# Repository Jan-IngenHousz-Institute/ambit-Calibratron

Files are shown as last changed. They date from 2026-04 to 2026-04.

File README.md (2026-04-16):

# Mini PAR meter - minimum tool to get a good numerical sense of light intensity

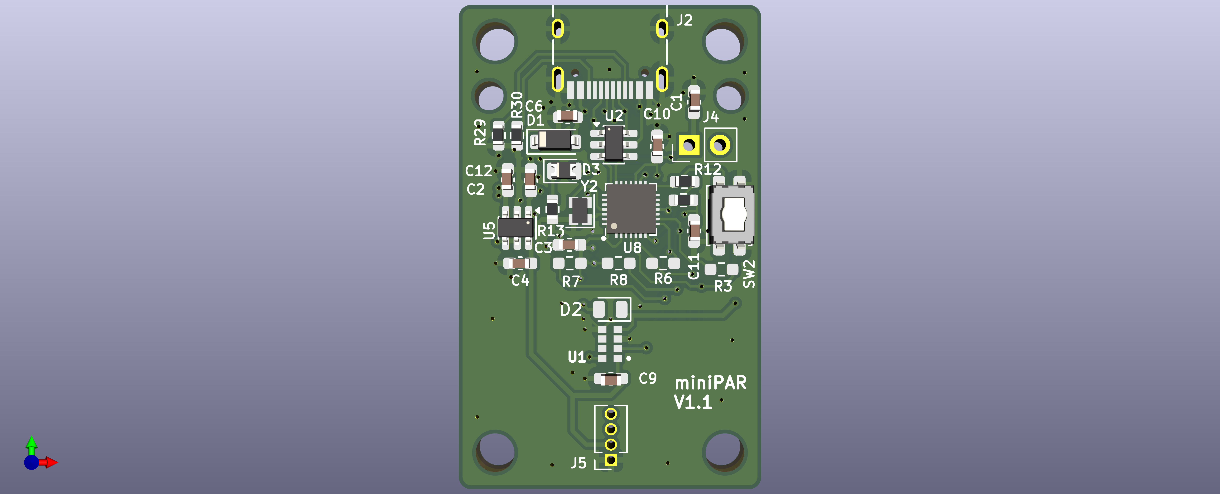
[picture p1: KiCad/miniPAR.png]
vis


# Commands

* to be added
* "reboot" -> 
    - Response: series of lines with info. 
    - ends with the "Ready" line
* "hello" -> 
    - Response: "MiniPAR,V" + version
* "spec" ->
    - Response: {"spectrometer":{"model":"AS7341","channels":{"f1_415":117,"f2_445":602,"f3_480":732,"f4_515":839,"f5_555":1606,"f6_590":1711,"f7_630":1765,"f8_680":1041,"clear":3704,"nir":359}}}
* "set_led"+ current value in mA ->
    - Response:  {"spectrometer":{"led_current_ma":20}} 
    - Example for 20mA
* "par" -> 
    - Response: 123.45
    - Read back par vale. This is a par_raw scaled by y=ax+b
* "par_raw"
    - Response: 1.23 
    - The weighted sum of the channel counts
* "cal_par_slope," + slope -> 
    - Response: 10.0
    - Example for slope = 10.0
    - Set the "a" coefficient for y=ax+b scaling
* "cal_par_ntercept," + intercept -> 
    - Response: 2.3
    - Example for intercept = 2.3
    - Set the "b" coefficient for y=ax+b scaling

# Protocol 

* terminator: "\r"
* PAR uinits - µmol/m²/s"

FW Design (L. Caracciolo),

HW Design (L. Grabowski)

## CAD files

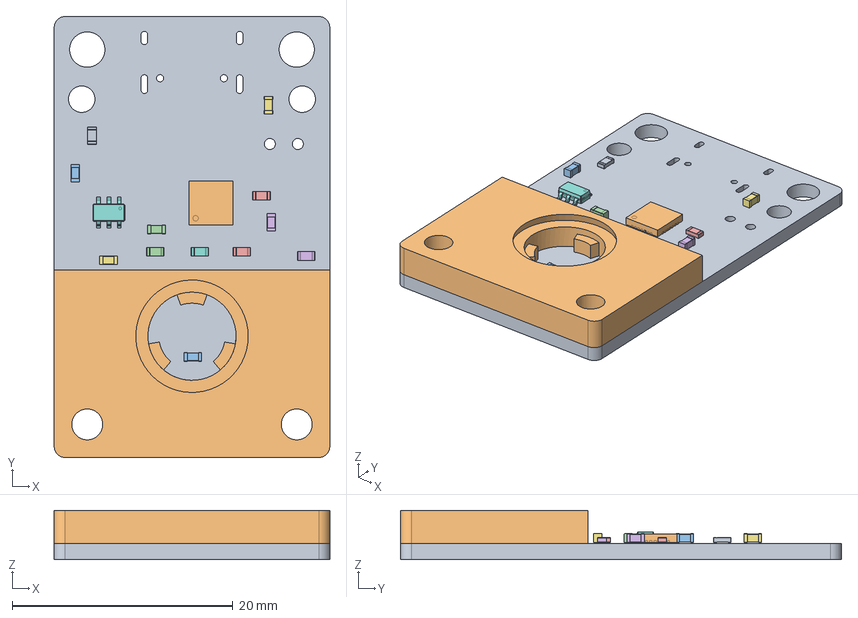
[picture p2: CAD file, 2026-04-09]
Case/diffuserHolder.FCStd
25.0 x 40.0 x 4.46 mm
caliTool_PCB
Insert
C_0603_1608Metric008
R_0603_1608Metric006
R_0603_1608Metric005
C_0603_1608Metric004
C_0603_1608Metric003
R_0603_1608Metric004
R_0603_1608Metric003
QFN-28-1EP_4x4mm_P0.4mm_EP2.4x2.4mm
C_0603_1608Metric002
C_0603_1608Metric001
R_0603_1608Metric002
R_0603_1608Metric001
C_0603_1608Metric
TSOT-23-6

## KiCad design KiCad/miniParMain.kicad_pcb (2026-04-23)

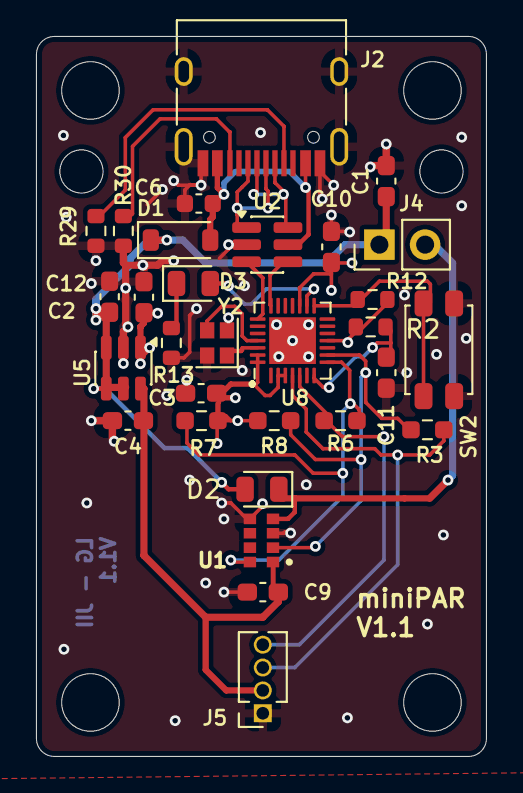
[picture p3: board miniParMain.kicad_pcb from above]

Board: 4 copper layers, 25.0 x 40.0 mm, 30 parts (0 on the bottom side), 22 nets.

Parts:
C1, C2, C3, C4, C9, C10, C11, C12: 2.2u; C_0603_1608Metric_Pad1.08x0.95mm_HandSolder
C6: 10u; C_0603_1608Metric
D1: 1N4148WT; D_SOD-123
D2, D3: LED; D_0805_2012Metric
J2: USB_C_Receptacle; USB_C_Receptacle_HRO_TYPE-C-31-M-12
J4: Conn_01x02_Pin; PinHeader_1x02_P2.54mm_Vertical
J5: secondBoard; PinSocket_1x04_P1.27mm_Vertical
R2, R12, R13, R29, R30: 5.1K; R_0603_1608Metric
R3, R6: 0R; R_0603_1608Metric_Pad0.98x0.95mm_HandSolder
R7, R8: 10K; R_0603_1608Metric_Pad0.98x0.95mm_HandSolder
SW2: SW_Push; SW_SPST_EVQP2_ShortPushTravel_H2.1mm
U1: AS7341-DLGT; PSON80P310X200X110-8N
U2: IP4234CZ6; SC-74-6_1.55x2.9mm_P0.95mm
U5: AP7312-1833W6-7; TSOT-23-6
U8: ESP8685; QFN-28-1EP_4x4mm_P0.4mm_EP2.6x2.6mm
Y2: 40MHz; Crystal_SMD_2016-4Pin_2.0x1.6mm

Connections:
BOOT: R12.1, SW2.1, U8.15 (GPIO9/BOOT)
CC1: J2.A5 (CC1), R29.2
CC2: J2.B5 (CC2), R30.2
D+: U2.3, U8.22 (GPIO19/USB_D+)
D-: U2.4, U8.21 (GPIO18/USB_D-)
GND: C1.2, C2.2, C3.2, C4.2, C6.1, C9.2, C10.2, C11.2, C12.2, J2.A1 (GND), J2.A12 (GND), J2.B1 (GND), J2.B12 (GND), J2.S1 (SHIELD), J5.1, R13.1, R29.1, R30.1, SW2.2, U1.3 (GND), U1.5 (PGND), U2.2 (VN), U5.2 (GND), U8.29 (GND), Y2.2, Y2.4
LED1ACT: D2.1 (K), J4.2, U1.4 (LDR)
unnamed: D3.2 (A), U8.16 (GPIO10)
unnamed: D3.1 (K), R13.2
unnamed: J2.A6 (D+), J2.B6 (D+), U2.1
unnamed: J2.A7 (D-), J2.B7 (D-), U2.6
unnamed: U8.25 (XTAL_N), Y2.3
unnamed: U8.26 (XTAL_P), Y2.1
SCL: R3.2, R8.1, U1.2 (SCL), U8.9 (MTMS/GPIO4/ADC1_CH4)
SCL_2: J5.4, R6.1, U8.5 (GPIO1/XTAL_32K_N/ADC1_CH1)
SDA: R6.2, R7.1, U1.8 (SDA), U8.8 (GPIO3/ADC1_CH3)
SDA_2: J5.3, R3.1, U8.4 (GPIO0/XTAL_32K_P/ADC1_CH0)
V+: C1.1, C12.1, D1.1 (K), D2.2 (A), J4.1, U5.3 (EN2), U5.4 (EN1), U5.5 (VIN)
V+1.8V: C4.1, C9.1, J5.2, U1.1 (VDD), U5.6 (VOUT_1V8)
V+3V: C2.1, C3.1, C10.1, R2.1, R7.2, R8.2, R12.2, U5.1 (VOUT_3V3), U8.2 (VDD3P3), U8.3 (VDD3P3), U8.11 (VDD3P3_RTC), U8.17 (VDD3P3_CPU), U8.27 (VDDA), U8.28 (VDDA)
Vusb: C6.2, D1.2 (A), J2.A4 (VBUS), J2.A9 (VBUS), J2.B4 (VBUS), J2.B9 (VBUS), U2.5 (VP)
reset_EN: C11.1, R2.2, U8.7 (CHIP_EN)

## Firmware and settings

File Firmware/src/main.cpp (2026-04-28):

#include <Arduino.h>
#include <Wire.h>
#include "app/commands.h"
#include "app/spectrometer_api.h"


String line;
enum class RxMode { UNKNOWN, LINE, JSON };
String rx;
RxMode mode = RxMode::UNKNOWN;
int braceDepth = 0;   // {}
int bracketDepth = 0; // []
bool inString = false;
char prev = 0;

void resetRx() {
  rx = "";
  mode = RxMode::UNKNOWN;
  braceDepth = 0;
  bracketDepth = 0;
  inString = false;
  prev = 0;
}

void setup() {
  
  Serial.begin(115200);

  Wire.begin(3, 4);
  
  loadpref();
  // Spectrometer detection and backend initialization
  initSpectrometer();
  Serial.println(F("Ready"));

  

}
 


void loop() {
while (Serial.available() > 0) {
    char c = (char)Serial.read();
    if (c == '\r')
      continue;

    rx += c;

    // Decide mode once we see the first non-whitespace char
    if (mode == RxMode::UNKNOWN) {
      // find first non-space char in the current buffer
      int i = 0;
      while (i < (int)rx.length() && isspace((unsigned char)rx[i]))
        i++;
      if (i < (int)rx.length()) {
        char first = rx[i];
        if (first == '{' || first == '[') {
          mode = RxMode::JSON; // start JSON mode (typically openJII app series of commands)
        } else {
          mode = RxMode::LINE; // start LINE mode (simple single-line commands)
        }
      }
    }

    // LINE mode: only process on newline
    if (mode == RxMode::LINE) {
      if (c == '\n') {
        rx.trim();
        if (rx.length() > 0)
          handleCommandText(rx);
        Serial.println();
        resetRx();
      }
      continue;
    }

    // JSON mode: track braces/brackets until outermost closes
    if (mode == RxMode::JSON) {
      if (c == '"' && prev != '\\')
        inString = !inString;

      if (!inString) {
        if (c == '{')
          braceDepth++;
        else if (c == '}')
          braceDepth--;
        else if (c == '[')
          bracketDepth++;
        else if (c == ']')
          bracketDepth--;
      }

      prev = c;

      // Only declare "complete" after the top-level JSON object/array closes.
      if (!inString && braceDepth == 0 && bracketDepth == 0) {
        rx.trim();
        bool ok = handleJsonProtocol(rx);
        if (!ok)
          Serial.println(F("{\"error\":\"json_dispatch_failed\"}"));
        resetRx();
      }
      continue;
    }

    // Safety: prevent runaway buffer
    if (rx.length() > 2048) {
      Serial.println("rx_overflow");
      resetRx();
    }
  }
}

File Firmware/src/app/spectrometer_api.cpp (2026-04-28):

#include <Arduino.h>
#include <Wire.h>
#include <Preferences.h>

#include "app/as7341_api.h"
#include "app/as7343_api.h"
#include "app/spectrometer_api.h"

// ---------------------------------------------------------------------------
// Global state
// ---------------------------------------------------------------------------
bool spectrometer_available = false;
SpectrometerModel spectrometer_model = SpectrometerModel::None;

// Transitional shim: keep as7341_available for the Phase 2 if-else command path.
// Removed in Phase 3 once the dispatch table takes over.
bool as7341_available = false;

// ---------------------------------------------------------------------------
// Board-level LED policy
// ---------------------------------------------------------------------------
constexpr uint16_t kSpectrometerLedBoardMaxMa = 20;
constexpr uint16_t kLedSetFailed = 0xFFFF;

// ---------------------------------------------------------------------------
// Channel name tables
// ---------------------------------------------------------------------------
static const char * const kAs7341ChannelNames[10] = {
  "f1_415", "f2_445", "f3_480", "f4_515",
  "f5_555", "f6_590", "f7_630", "f8_680",
  "clear",  "nir"
};

// AS7343 bringup names — 18 entries matching Adafruit as7343_channel_t DATA register order.
// Used when channel_count == 18 (AS7343_BRINGUP_RAW_DUMP active).
// DELETE together with the bringup path once the semantic table is frozen.
static const char * const kAs7343BringupNames[18] = {
  "fz_450",    // DATA[0]  FZ  450nm
  "fy_555",    // DATA[1]  FY  555nm
  "fxl_600",   // DATA[2]  FXL 600nm
  "nir",       // DATA[3]  NIR 855nm
  "vis_tl_0",  // DATA[4]  VIS clear cycle 1 top-left
  "vis_br_0",  // DATA[5]  VIS clear cycle 1 both-right
  "f2_425",    // DATA[6]  F2  425nm
  "f3_475",    // DATA[7]  F3  475nm
  "f4_515",    // DATA[8]  F4  515nm
  "f6_640",    // DATA[9]  F6  640nm
  "vis_tl_1",  // DATA[10] VIS clear cycle 2 top-left
  "vis_br_1",  // DATA[11] VIS clear cycle 2 both-right
  "f1_405",    // DATA[12] F1  405nm
  "f7_690",    // DATA[13] F7  690nm
  "f8_745",    // DATA[14] F8  745nm
  "f5_550",    // DATA[15] F5  550nm
  "vis_tl_2",  // DATA[16] VIS clear cycle 3 top-left
  "vis_br_2",  // DATA[17] VIS clear cycle 3 both-right
};

// AS7343 semantic names — 13 entries for production mode (channel_count == 13).
// Channels sorted wavelength-ascending; clear derived from VIS averages; nir last.
// TODO: confirm this ordering from bring-up evidence before switching off bringup mode.
static const char * const kAs7343ChannelNames[13] = {
  "f1_405",   // F1  405nm
  "f2_425",   // F2  425nm
  "fz_450",   // FZ  450nm
  "f3_475",   // F3  475nm
  "f4_515",   // F4  515nm
  "f5_550",   // F5  550nm
  "fy_555",   // FY  555nm
  "fxl_600",  // FXL 600nm
  "f6_640",   // F6  640nm
  "f7_690",   // F7  690nm
  "f8_745",   // F8  745nm
  "clear",    // derived from VIS averages
  "nir",      // NIR 855nm
};


//float par_coefficients[18] = {0}; // per-channel PAR conversion coefficients, indexed 0..channel_count-1. 18 = AS7343 bringup max
// default values for AS7341 from datasheet
float par_coefficients[18] = {
  1.0/55.0, 
  1.0/110.0, 
  1.0/214.0, 
  1.0/390.0, 
  1.0/590.0, 
  1.0/840.0, 
  1.0/1350.0, 
  1.0/1070.0, 
  0,0,0,0,0,0,0,0,0,0}; // per-channel PAR conversion coefficients, indexed 0..channel_count-1. 18 = AS7343 bringup max

  Preferences preferences; // for storing persistent settings like PAR coefficients

float slope = 0;
float intercept = 0;
char dev_name[20] = "NoName";

void loadpref() {
  preferences.begin("par_coeffs", true);
  
  // for a future phase: if we want to support per-channel PAR coefficients, we can store them in preferences with keys like "ch0", "ch1", etc. For now, just store slope and intercept for a single linear conversion. 
  //for (int i = 0; i < 18; i++) {
  //  char key[6];
  //  snprintf(key, sizeof(key), "ch%d", i);
  //  par_coefficients[i] = preferences.getFloat(key, par_coefficients[i], 0.0);
  //}
  
  slope = preferences.getFloat("slope", 1.0f);
  intercept = preferences.getFloat("intercept", 0.0f);
  if(preferences.isKey("name"))
  {
    preferences.getString("name", dev_name, 20);
    dev_name[sizeof(dev_name) - 1] = '\0';
  } 
  preferences.end();
}

namespace {

// ---------------------------------------------------------------------------
// Detection helpers
// ---------------------------------------------------------------------------
constexpr uint8_t  kSpectrometerI2cAddress    = 0x39;
constexpr uint32_t kProbeRetryWindowUs         = 5000;
constexpr uint32_t kProbeRetryIntervalUs        = 250;
constexpr bool     kSpectrometerDetectionDebug  = true;

struct DetectionResult {
  SpectrometerModel model = SpectrometerModel::None;
  bool saw_ack = false;
};

struct DetectionDebugInfo {
  uint32_t attempts = 0;
  bool saw_ack = false;
  bool as7343_id_read_ok = false;
  uint8_t as7343_chip_id = 0;
  bool as7341_id_read_ok = false;
  uint8_t as7341_chip_id = 0;
};

void syncLegacyAvailability() {
  as7341_available =
      spectrometer_available && spectrometer_model == SpectrometerModel::AS7341;
}

void setSpectrometerState(SpectrometerModel model, bool available) {
  spectrometer_model    = model;
  spectrometer_available = available;
  syncLegacyAvailability();
}

bool spectrometerAddressAcks() {
  Wire.beginTransmission(kSpectrometerI2cAddress);
  return Wire.endTransmission() == 0;
}

void printHexByte(uint8_t value) {
  if (value < 0x10) Serial.print('0');
  Serial.print(value, HEX);
}

void printDetectionDebug(const char *reason, const DetectionDebugInfo &debug,
                         SpectrometerModel result_model, bool initialized) {
  if (!kSpectrometerDetectionDebug) return;
  Serial.print(F("[spectrometer-debug] reason="));
  Serial.print(reason);
  Serial.print(F(" attempts="));
  Serial.print(debug.attempts);
  Serial.print(F(" ack="));
  Serial.print(debug.saw_ack ? F("1") : F("0"));
  Serial.print(F(" as7343_id_ok="));
  Serial.print(debug.as7343_id_read_ok ? F("1") : F("0"));
  Serial.print(F(" as7343_id=0x"));
  printHexByte(debug.as7343_chip_id);
  Serial.print(F(" as7341_id_ok="));
  Serial.print(debug.as7341_id_read_ok ? F("1") : F("0"));
  Serial.print(F(" as7341_id=0x"));
  printHexByte(debug.as7341_chip_id);
  Serial.print(F(" result="));
  Serial.print(spectrometerModelName(result_model));
  Serial.print(F(" init_ok="));
  Serial.println(initialized ? F("1") : F("0"));
}
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

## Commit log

2026-04-08 add kicad files - V1.0
    [miniParMain.kicad_pcb, miniParMain.kicad_sch]
2026-04-09 PCB revision -> V 1.1
    [miniParMain.kicad_pcb, miniParMain.kicad_sch]
2026-04-09 add bare minimum casing - diffuser holder
    [diffuserHolder.FCStd]
2026-04-16 add direct PAR readout and option to scale and calibrate dec
2026-04-28 added JSON parsing feature, bug MCU not supported by openJII
    [as7341_api.cpp, commands.cpp, debug_api.cpp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]
